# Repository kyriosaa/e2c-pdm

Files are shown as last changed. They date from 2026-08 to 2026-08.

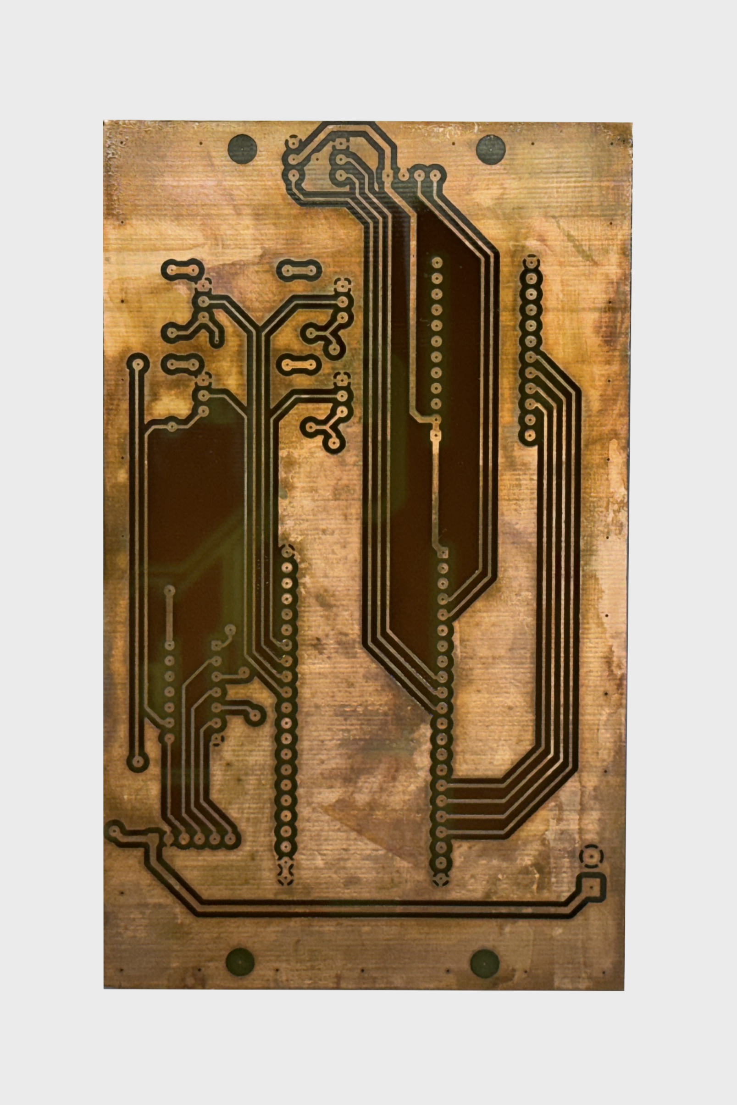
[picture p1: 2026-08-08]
docs/images/rev2.0/mdc_2.1_back.png

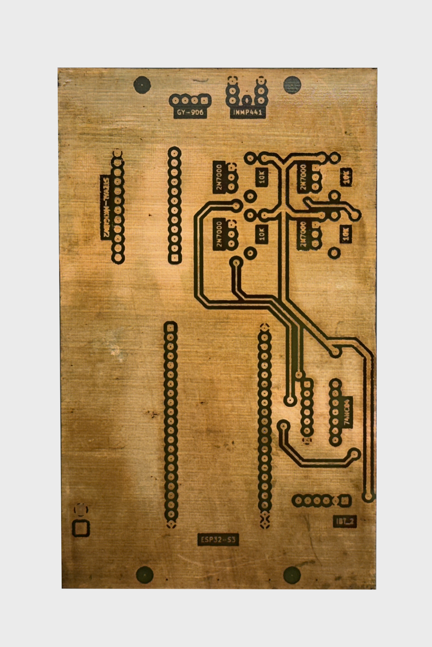
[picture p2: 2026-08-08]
docs/images/rev2.0/mdc_2.1_front.png

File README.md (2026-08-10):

# E2C-PDM — An edge-to-cloud digital twin for predictive maintenance

Thesis project. A three-tier condition-monitoring system built around a
laboratory motor rig: an ESP32-S3 acquisition front-end, a Raspberry Pi
inference tier, and a cloud tier for the digital twin and long-horizon storage.

**Status: data acquisition validated, healthy baseline recorded, no fault data
yet.** The offline feature pipeline runs end to end. Model training is blocked on
seeded-fault data — see
[docs/notes/collection_protocol.md](docs/notes/collection_protocol.md).

---

## Architecture

```
   MOTOR RIG                 EDGE TIER 1            EDGE TIER 2        CLOUD
   ---------                 -----------            -----------        -----
  RS-445PA DC motor
  + BTS7960 driver
        |
  IIS3DWB   26.7 kHz x3 ---+
  INMP441   16 kHz mono ---+--> ESP32-S3 ----USB CDC----> Raspberry Pi ---> InfluxDB
  MLX90614  1 Hz -------- +    (FreeRTOS,   ~200 KB/s    (features,        + digital
                               2 cores,                   inference,         twin
                               raw counts)                cascade gate)
                                    |
                            thermal interlock
                            70 C latched kill
```

Design principle: computation is pushed to the cheapest place. The MCU ships raw
sensor counts and does no unit conversion or feature extraction, which keeps it a
deterministic acquisition front-end and keeps the acquisition path identical
between dataset collection and deployment.

The ESP32→Pi link is infrastructure and is **excluded** from the bandwidth-savings
claim; that claim applies to the Pi→cloud tier only.

## Repository layout

```
edge/
  esp32/firmware/mdc/                  acquisition + safety firmware
  esp32/tools/                         data_catcher.py (host logger), notifier, start_handler
  hardware/edge_asset_monitor_2L/      2-layer PCB, lab-etched (KiCad)
  hardware/edge_asset_monitor_4L/      4-layer PCB + gerbers (KiCad)
  hardware/espressif-kicad-addon/      VENDORED third-party library, see its README
  rpi/                                 Pi-tier scaffolding (early)
cloud/                                 cloud-tier scaffolding (early)
ml/                                    offline pipeline -- see ml/README.md
  studies/                             one-off analyses (audio filtering, integrity)
  notebooks/                           exploratory notebooks
data/                                  UNTRACKED. raw/ interim/ processed/
docs/
  notes/                               decisions + rationale + the quirk
                                       register. READ THIS FIRST.
  figures/                             tracked thesis figures (pipeline/ is generated)
  datasheets/ certifications/          RS-445PA, IIS3DWB, STEVAL-MKI208V1K,
                                       ISO 13732-1, ...
  schematics/ images/                  rev1.0 and rev2.0
references.md                          reference paper bank
```

`data/` is gitignored; sessions are ~4.5 GB each. `docs/notes/` is gitignored
too, so **the design notes linked below are local-only and will not be present
in a clone.** `docs/figures/pipeline/` is gitignored as the pipeline regenerates
it; the rest of `docs/` is tracked.

## Getting oriented

Start with [docs/notes/](docs/notes/):

| Note | What it settles |
|---|---|
| [quirk_register.md](docs/notes/quirk_register.md) | **Read before quoting any number.** The real dataset inventory, known defects, and the measured sensor calibration. |
| [collection_protocol.md](docs/notes/collection_protocol.md) | **How to collect data from here on.** The confound trap, the fault set, the integrity gate. |
| [operating_profile_rationale.md](docs/notes/operating_profile_rationale.md) | Why the rig needs no "real" use case, and what it does need. |
| [motor_signature.md](docs/notes/motor_signature.md) | Measured spectrum, measured sample rates, rig validation against physics. |
| [thermal_channel_confound.md](docs/notes/thermal_channel_confound.md) | Why absolute temperature is unusable and the thermal channel is currently flat. |
| [acoustic_noise_filtering.md](docs/notes/acoustic_noise_filtering.md) | Why spectral subtraction, and why not a notch or high-pass. |
| [overnight_acquisition_rig.md](docs/notes/overnight_acquisition_rig.md) | Acquisition architecture, integrity layers, safety layers, defence Q&A. |
| [thermal_interlock_70c.md](docs/notes/thermal_interlock_70c.md) | Why 70 °C, from ISO 13732-1. |

## Reproducing a recording session

Requires the physical rig. Read
[overnight_acquisition_rig.md](docs/notes/overnight_acquisition_rig.md) §3
before running unattended.

1. Flash `edge/esp32/firmware/mdc/` to the ESP32-S3.
   **Never flash with the 24 V rail energised.** Power sequence: USB first, 24 V
   last; de-energise 24 V first.
2. Set the run parameters and provenance fields at the top of
   `edge/esp32/tools/data_catcher.py` — `SESSION_LABEL`, `RUN_SECONDS`,
   `MOTOR_VOLTAGE_V`, `MECHANICAL_LOAD`, `FAULT_CONDITION`, `ROOM_CONDITION`.
   `ACCEL_FS_G` must match the firmware.
3. `python edge/esp32/tools/data_catcher.py`
   The motor arms after `ARM_DELAY_S` (60 s); that head of the recording is the
   motor-off room-noise reference. No logger means no motor — the firmware
   requires an explicit host arm.
4. Output lands in `data/raw/<label>_<timestamp>/`: `vibration.bin`, `audio.wav`,
   `status.csv`, `packet_index.csv`, `session.json`.
5. Gate the session on integrity before trusting it:
   ```
   python -m ml.sessions <session_name>
   python -m ml.studies.integrity_report
   ```
   Acceptance criteria are in
   [collection_protocol.md](docs/notes/collection_protocol.md).

## Running the offline pipeline

From the repository root. See [ml/README.md](ml/README.md) for detail.

```
pip install -r ml/requirements.txt

python -m ml.sessions                 # gap map + measured sample rates (cached)
python -m ml.data_loader              # per-session sanity check
python -m ml.features                 # gap-aware Welch PSD windows
python -m ml.studies.integrity_report # dataset integrity table

# leave-one-session-out, training pool held to one operating point so the 15 V
# session stays unseen for the novelty check
python -m ml.train_autoencoder --split session \
    --sessions healthy24V_motor_baseline_20260718_001741 \
               healthy24V_motor_baseline_20260719_010905 \
    --holdout  healthy24V_motor_baseline_20260719_010905
python -m ml.evaluate --novelty healthy15V_motor_baseline_20260716_002156
python -m ml.quantize                 # TFLite dynamic + int8
```

Feature extraction needs only numpy + scipy. **Training needs TensorFlow, which
has no Python 3.14 wheels** — use a separate 3.12 environment for the last three
steps; cached features are reusable across both. See ml/README.md.

## Secrets

Copy `.env.example` to `.env` and fill it in. `.env` is gitignored and is the only
place credentials belong.

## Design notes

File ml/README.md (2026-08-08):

# ml/ — offline ML pipeline

Consumes sessions recorded by `edge/esp32/tools/data_catcher.py` from
`data/raw/`, and produces model artifacts for the edge tier.

```
ml/
├── config.py             all knobs; repo-root anchored paths
├── sessions.py           gap map, measured sample rates, status log   <- read this first
├── data_loader.py        memory-mapped session access
├── features.py           gap-aware Welch PSD windows
├── train_autoencoder.py  leave-one-session-out or time split
├── evaluate.py           thresholds, false-positive rate, novelty check
├── quantize.py           TFLite dynamic + int8, accuracy/threshold drop table
├── studies/              one-off analyses (audio filtering, integrity report)
└── notebooks/            exploratory
```

Generated output lives outside the package:

```
data/interim/<session>/index.json      cached gap map + measured rates
data/interim/features/<session>/       cached feature windows
ml/artifacts/                          models, scaler, tflite (gitignored)
docs/figures/pipeline/                      diagnostic plots (gitignored)
docs/figures/<study>/                       tracked thesis figures
```

## Run everything as a module, from the repo root

```
python -m ml.sessions
```

Not `python ml/sessions.py`. The package uses relative imports, and every path in
`config.py` resolves from the repository root rather than the working directory,
so results do not depend on where you happen to be standing.

## Python version — read before installing

**Feature extraction needs only numpy + scipy** and runs on any modern Python,
including 3.14.

**Training, evaluation and quantization need TensorFlow, which does not publish
wheels for Python 3.14.** Those three steps will exit with instructions if TF is
missing. Use a separate 3.12 environment for them:

```
py -3.12 -m venv .venv-train
.venv-train\Scripts\activate
pip install -r ml/requirements.txt
```

Cached features under `data/interim/features/` are plain `.npy` and are shared
between both environments, so there is no need to re-extract.

## Run order

```
pip install -r ml/requirements.txt

# 1. Parse packet_index.csv -> gap map + measured sample rates. Cached; the
#    first run takes ~10 s per session for a 366 MB index.
python -m ml.sessions

# 2. Per-session sanity check: measured ODR, full scale, segment count,
#    motor-off vs running RMS.
python -m ml.data_loader [session]

# 3. Feature windows. ~1.5 min per 6 h session.
python -m ml.features [session ...]

# 4. Train. --split session is leave-one-session-out and is the number to report.
#    Restrict the training pool to ONE operating point so the other stays unseen
#    and can serve as the novelty check. With the three pilot sessions:
python -m ml.train_autoencoder --split session \
    --sessions healthy24V_motor_baseline_20260718_001741 \
               healthy24V_motor_baseline_20260719_010905 \
    --holdout  healthy24V_motor_baseline_20260719_010905

# 5. Thresholds + false-positive rate. --novelty scores the 15 V session, which
#    the model has never seen, as an off-manifold sensitivity check.
python -m ml.evaluate --novelty healthy15V_motor_baseline_20260716_002156

# 6. TFLite export, accuracy drop, and threshold shift under quantization.
python -m ml.quantize

# Anytime: the dataset integrity table.
python -m ml.studies.integrity_report [--markdown]
```

## Three things that are easy to get wrong

**1. `vibration.bin` has no framing and no gap markers.** `data_catcher.py`
validates the header and CRC in memory, then writes *only* the payload. Lost
packets are simply absent, so the file is a splice of discontinuous runs. Cutting
an FFT window across a splice fabricates a broadband transient that looks exactly
like an impulsive mechanical fault. `sessions.contiguous_segments()` is the only
safe source of window offsets.

On-device FIFO overruns are the nastier version of this: samples vanish inside
the sensor while the packet sequence stays perfectly contiguous, so they are
invisible to sequence-gap detection. The segment map breaks on the overrun flag
for exactly this reason.

**2. Never use a nominal sample rate.** The IIS3DWB measures 26 533–26 547 Hz
against a 26 667 Hz datasheet nominal — it runs ~0.45 % slow, consistently. On the
same host clock the audio stream is accurate to a few ppm, which localises the
error to the sensor's oscillator. At nominal the frequency axis is wrong by 2.9 Hz
at the 635 Hz peak. `sessions.measured_odr()` derives the rate from sequence
numbers and host timestamps, which makes it immune to packet loss and to MCU
resets.

**3. Accelerometer full scale is per session.** The pilot sessions were recorded
at ±16 g; everything from 2026-07-30 is ±4 g. `session.json` carries `accel_fs_g`,
and `sessions.accel_fs_g()` falls back by start timestamp for the pilot sessions.
It raises rather than guessing for anything ambiguous. Do not hardcode it.

## Memory

Everything is memory-mapped and converted per window. A 6 h session is 3.2 GB of
int16 vibration; materialising it as float32 `(N, 3)` would need ~7 GB on top of
the raw bytes, so `load_vibration`-style whole-file loading is deliberately absent.
`load_audio()` still reads a whole track (~1.4 GB as float32) because the audio
studies want it; prefer `open_audio()` plus `audio_to_float()` on slices.

## What the current results can and cannot claim

Can: measured rig characterisation, dataset integrity figures, a healthy-data
false-positive operating point, and a sensitivity-to-change demonstration
(train on 24 V, score 15 V).

Cannot: any detection rate, ROC or AUC. There is no fault data. See
[../docs/notes/collection_protocol.md](../docs/notes/collection_protocol.md).

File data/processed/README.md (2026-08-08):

# data/processed/ — analysis-ready derived datasets (untracked)

Reserved for datasets that are downstream of feature extraction and worth
persisting in their own right (e.g. an assembled train/test matrix spanning
several sessions, or denoised audio exports).

Note the distinction from `docs/figures/`: **figures are thesis artifacts and are
tracked**; processed data is an intermediate and is not.

Currently empty.

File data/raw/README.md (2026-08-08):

# data/raw/ — recorded sessions (untracked)

One directory per recording, named `<label>_<YYYYmmdd_HHMMSS>_<Day>`, written by
`edge/esp32/tools/data_catcher.py`. Roughly **4.5 GB per 6-hour session**.

The weekday is a convenience for scanning the directory listing and carries no
meaning downstream. Two constraints it works around: the label stays first
because `ml.train_autoencoder.operating_point()` keys on the first `_`-separated
field, and `session.json`'s `started` stays a bare timestamp because
`ml.sessions.accel_fs_g()` string-compares it against `ACCEL_FS_CHANGED_AFTER`.
The six pilot sessions predate the weekday and keep their original names.

Never renamed after recording: the cached index in `data/interim/<session>/` is
keyed on the directory name.

## Getting sessions onto the analysis machine

Recording happens on a separate machine from analysis, and this directory is
untracked, so sessions travel by removable drive. **Do not drag-and-drop** — use
the export tool, which SHA-256s every file as it writes and leaves the digests
in `export_manifest.json` alongside the data:

```
# recording machine -> drive
python edge/esp32/tools/export_sessions.py E:/pdm_transfer --skip-tests

# analysis machine: copy the drive's contents into data/raw/, including
# export_manifest.json, then verify the copy you will actually use
python edge/esp32/tools/export_sessions.py data/raw --verify
```

Verify `data/raw`, not the drive — verifying the drive only proves the drive is
intact and says nothing about the second copy.

`--verify` exits non-zero on any mismatch, and re-running the export skips files
already present, so an interrupted transfer resumes. Verify before deleting the
source copy: `vibration.bin` is unframed int16 with no checksum of its own, so a
corrupted byte range is indistinguishable from a real impulsive transient once
it reaches the feature extractor.

## Files per session

| File | Contents |
|---|---|
| `vibration.bin` | Bare little-endian int16 x,y,z triplets. **No framing, no gap markers.** Scale with `accel_fs_g` from `session.json`. |
| `audio.wav` | 16 kHz 16-bit mono. First ~60 s is motor-off room reference. |
| `status.csv` | ~0.977 Hz log: obj/amb temperature, motor state, fault code, counters. |
| `packet_index.csv` | Host arrival time, type, seq, n_samples, flags, dropped for **every** packet. This is what makes the gap map possible. ~366 MB. |
| `session.json` | Metadata + integrity summary + acquisition provenance. |

## Read this before analysing anything

`vibration.bin` holds payload bytes only — lost packets are simply absent, so the
file is a splice of discontinuous runs. Windowing across a splice fabricates a
broadband transient that mimics an impulsive fault. Use
`ml.sessions.contiguous_segments()`, never a naive `arange` over the file.

`session.json`'s `vib_capture_ratio` divides by the **nominal** 26 667 Hz ODR and
therefore understates completeness by the sensor's ~0.45 % clock error. For a real
integrity figure use the sequence-derived ratio from `ml.sessions` /
`ml.studies.integrity_report`.

## Current contents

Six 6-hour healthy baselines recorded 2026-07-16 to 07-20 at ±16 g full scale,
plus three short `test_*` rig-shakedown captures from 07-15/16 that are not
analysis data.

| Session | Motor | Capture ratio | CRC errors |
|---|---|---|---|
| `healthy15V_motor_baseline_20260716_002156` | 15 V | 0.9953 | 160 |
| `healthy24V_motor_baseline_20260718_001741` | 24 V | 0.9949 | 83 |
| `day_healthy24V_motor_baseline_20260718_170626` | 24 V, daytime room | 0.9953 | 123 |
| `healthy24V_motor_baseline_20260719_010905` | 24 V | 0.9955 | 115 |
| `healthy24V_motor_baseline_20260720_003416` | 24 V | 0.9946 | **5719** |
| `healthy24V_motor_baseline_20260720_231747` | 24 V | 0.9955 | 375 |

These are **rig validation / pilot data**, not the final healthy baseline: they
predate the ±4 g full-scale change and were recorded with no mechanical load.
See `docs/notes/collection_protocol.md`.

None of them carry the provenance fields (`accel_fs_g`, `motor_voltage_v`,
`mechanical_load`, `fault_condition`, `room_condition`, `notes`) — all six
predate `ACCEL_FS_CHANGED_AFTER`, so `ml.sessions.accel_fs_g()` resolves them to
±16 g by start timestamp. Voltage in the table above comes from the directory
name, which is the only record of it.

### Two things to check before trusting a session

`healthy24V_motor_baseline_20260720_003416` logged **5719 CRC errors**, roughly
50× every other session (5–375). Its capture ratio is normal, so the link was
recovering, but confirm the gap map from `ml.studies.integrity_report` before
using it — link trouble at that rate may have left more or larger splices.

Every `session.json` here also carries a **`measured_odr_hz` field that is not
authoritative**. It was backfilled as `vib_samples / elapsed_s`, which divides
real samples by wall-clock time and so folds packet loss into what looks like a
clock measurement. It happens to land close (26456–26546 Hz) because transport
loss was ~0.001 %, but it is the same conflation `vib_capture_ratio` is warned
about above. Use `ml.sessions.measured_odr()`, which derives the rate from
packet sequence numbers and separates the two.

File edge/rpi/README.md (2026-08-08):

# edge/rpi/ — Raspberry Pi inference tier

**Status: early. One working script, the rest is planned structure.**

The Pi is the inference tier of the cascade. It receives raw sensor counts from
the ESP32 over USB CDC, does unit conversion and feature extraction (deliberately
NOT done on the MCU), runs the local quantized model, and decides per window
whether the local prediction is confident enough or the window should be offloaded
to the cloud tier.

The Pi->cloud link is the one the bandwidth-savings claim applies to. The
ESP32->Pi link is infrastructure and is excluded from that calculation.

## What exists

| Path | Status |
|---|---|
| `pi_edge_twin.py` | **Working.** Subscribes to an MQTT topic, thresholds `rms_vibration`, writes breaches to InfluxDB 3. This is a functional spike of the confidence gate, not the final design. |
| `config/edge_config.py` | Empty stub. |
| `communications/` | Planned: `usb_listener.py`, `cloud_offload.py`. |
| `data_pipeline/` | Planned: `sensor_processor.py`. |
| `inference/` | Planned: `model.py`, `confidence_gate.py`, `alert_handler.py`. |

## Known gaps

- **`pi_edge_twin.py` uses a fixed `VIBRATION_THRESHOLD` on a single scalar RMS.**
  The offline pipeline in `ml/` produces a 1024-bin PSD feature vector and an
  autoencoder reconstruction error. These need to converge — the deployed gate
  should sit on the same feature and the same threshold the thesis derives in
  `ml/evaluate.py`, not on an unrelated hand-set RMS limit.
- **Two secret stores.** `pi_edge_twin.py` imports credentials from the untracked
  `edge/esp32/tools/private.py`; everything newer uses the gitignored `.env` at
  the repo root. Converge on `.env`.
- **Input path is MQTT, not USB.** The current script assumes something else is
  already publishing to MQTT. `communications/usb_listener.py` is the missing
  piece that would make the Pi read the ESP32 directly, matching the architecture
  described in the root README.

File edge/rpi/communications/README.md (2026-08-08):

# Planned

- `usb_listener.py` — read the framed packet stream from the ESP32 over USB CDC.
  The framing is already implemented host-side in
  `edge/esp32/tools/data_catcher.py`; this is that parser minus the file writing.
- `cloud_offload.py` — ship a window to the cloud tier when the local model is
  not confident. This is the link the bandwidth-savings claim measures.

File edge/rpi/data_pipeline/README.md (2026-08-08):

# Planned

- `sensor_processor.py` — raw int16 counts to engineering units, then windowing
  and Welch PSD features.

Must produce **byte-identical features** to `ml/features.py`, or the deployed
model sees a different distribution than it trained on. Import the offline code
rather than reimplementing it; scale using `accel_fs_g` and the measured ODR, not
datasheet nominals (see `ml/README.md`).

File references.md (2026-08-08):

# Bank of reference papers that I've used so far

Calculation of Printed Circuit Board Power Loop Stray Inductance in GaN or High di/dt Applications
https://ieeexplore.ieee.org/document/8337781
> Paper about how the physical geometry and width of the PCB traces directly dictate parasitic stray inductance. Confirms that the only way to prevent overvoltage ringing and electromagnetic interference is by placing ground lines around the PCB and minimizing the magnetic loop area.

Study and Implementation of IIR Notch Filter and Its Applications
https://www.researchgate.net/publication/380544131_Study_and_Implementation_of_IIR_Notch_Filter_and_Its_Applications

High Pass Filter Designation and IT Report
https://www.researchgate.net/publication/236615957_HIGH_PASS_FILTER_DESIGNATION_AND_IT_REPORT

Noise Removal in Speech Processing Using Spectral Subtraction
https://www.researchgate.net/publication/220841101_Noise_Removal_in_Speech_Processing_Using_Spectral_Subtraction

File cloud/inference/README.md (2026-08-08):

# Planned

- `model.py` — the full-precision cloud model.
- `inference_service.py` — API endpoint the Pi offloads to.

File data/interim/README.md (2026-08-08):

# data/interim/ — generated caches (untracked)

Everything here is derived and safe to delete; it will be rebuilt.

```
<session>/index.json    cached gap map, measured sample rates, loss stats
                        (ml.sessions -- rebuild with --rebuild)
features/<session>/     cached feature windows as .npy + meta.json
                        (ml.features)
```

`index.json` is keyed on the session directory name, so renaming a session
orphans its cache. `ml/sessions.py` bumps `CACHE_VERSION` whenever the index
format or segmentation logic changes, which invalidates stale caches
automatically.

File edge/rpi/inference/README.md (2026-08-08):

# Planned

- `model.py` — load and run the int8 TFLite autoencoder from `ml/artifacts/`.
- `confidence_gate.py` — threshold the reconstruction error to decide local vs
  cloud. Use the threshold derived on the **quantized** model
  (`ml/quantize.py` reports both); a float-derived threshold does not keep its
  false-positive rate after quantization.
- `alert_handler.py` — act on confident local detections.

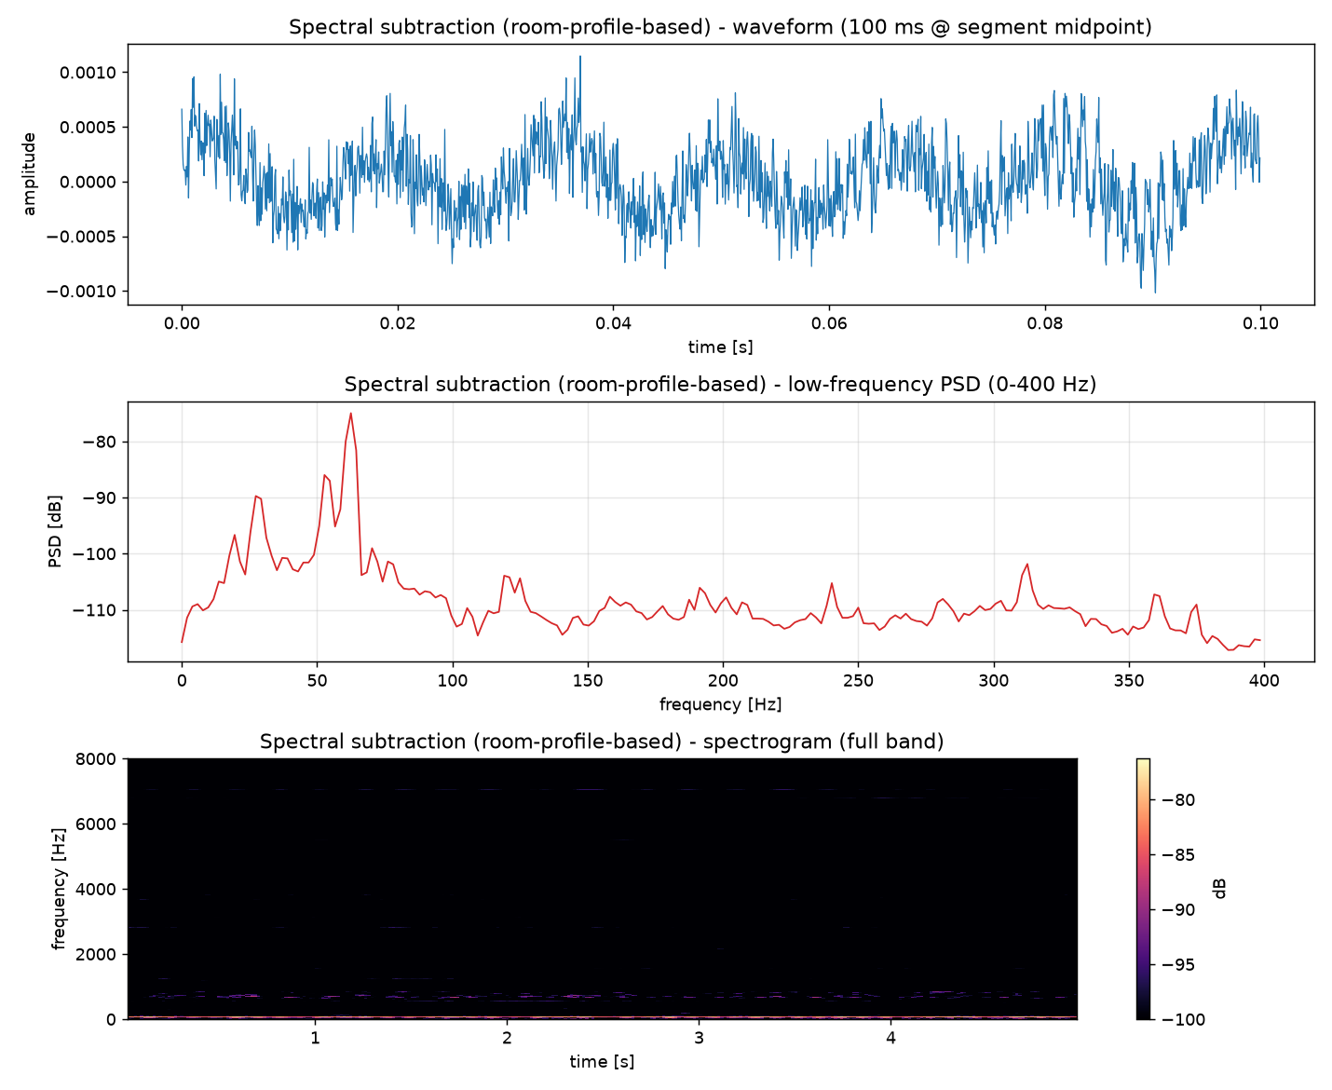
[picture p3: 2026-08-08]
docs/figures/audio_filtering/filter_compare_4way/motor_04_spectral_subtraction.png

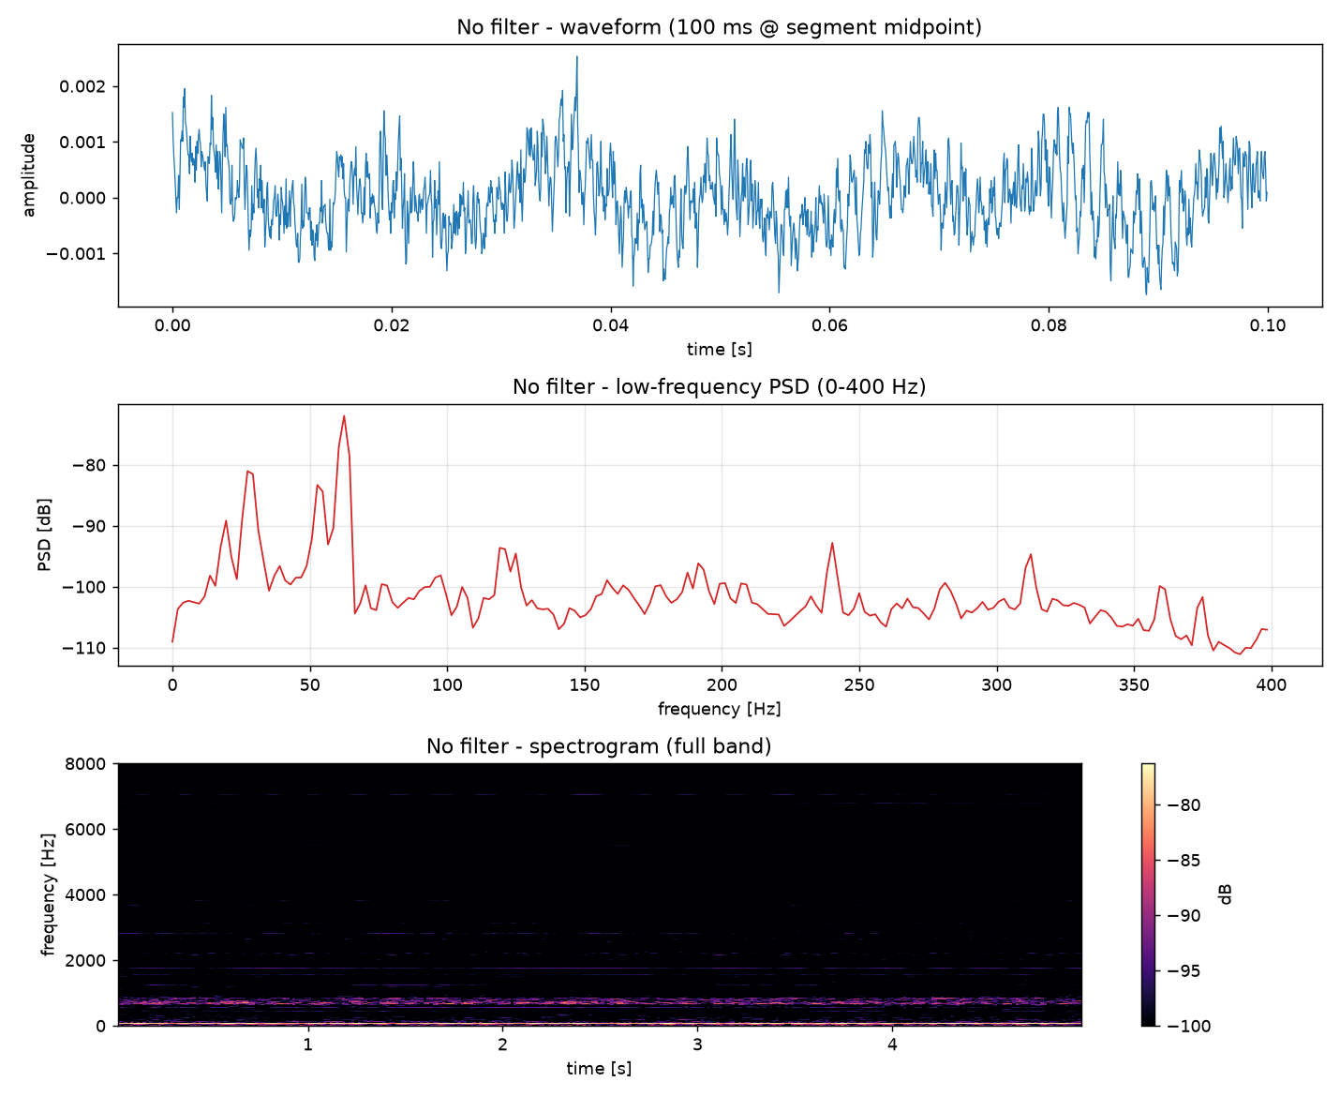
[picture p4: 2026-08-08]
docs/figures/audio_filtering/filter_compare_4way/motor_01_no_filter.png

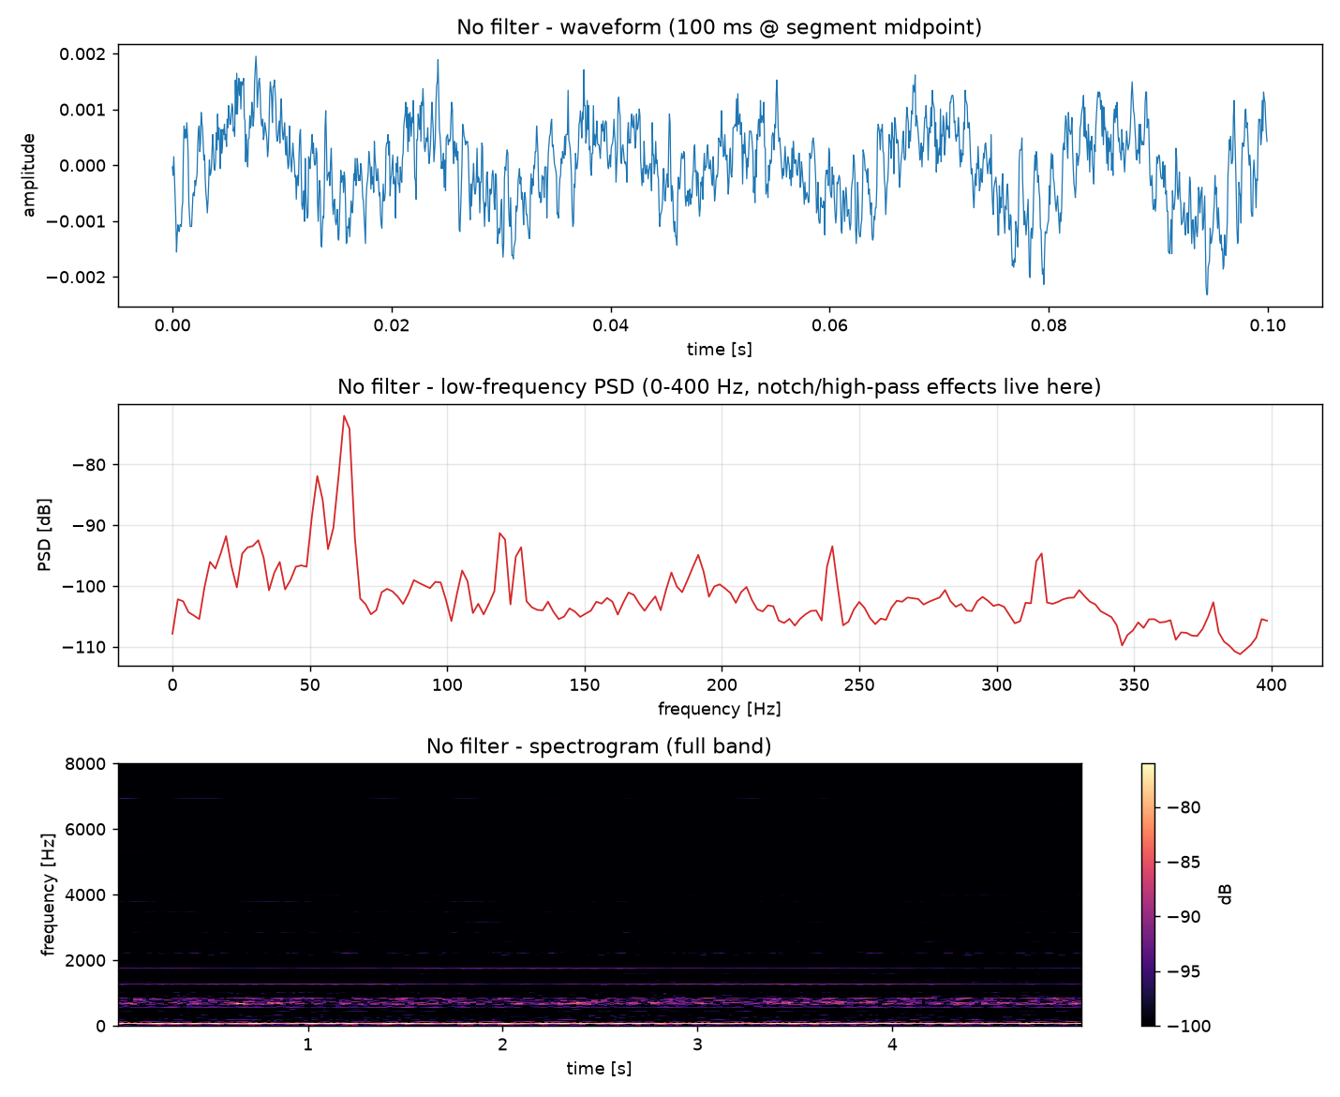
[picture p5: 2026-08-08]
docs/figures/audio_filtering/filter_demo/01_no_filter.png

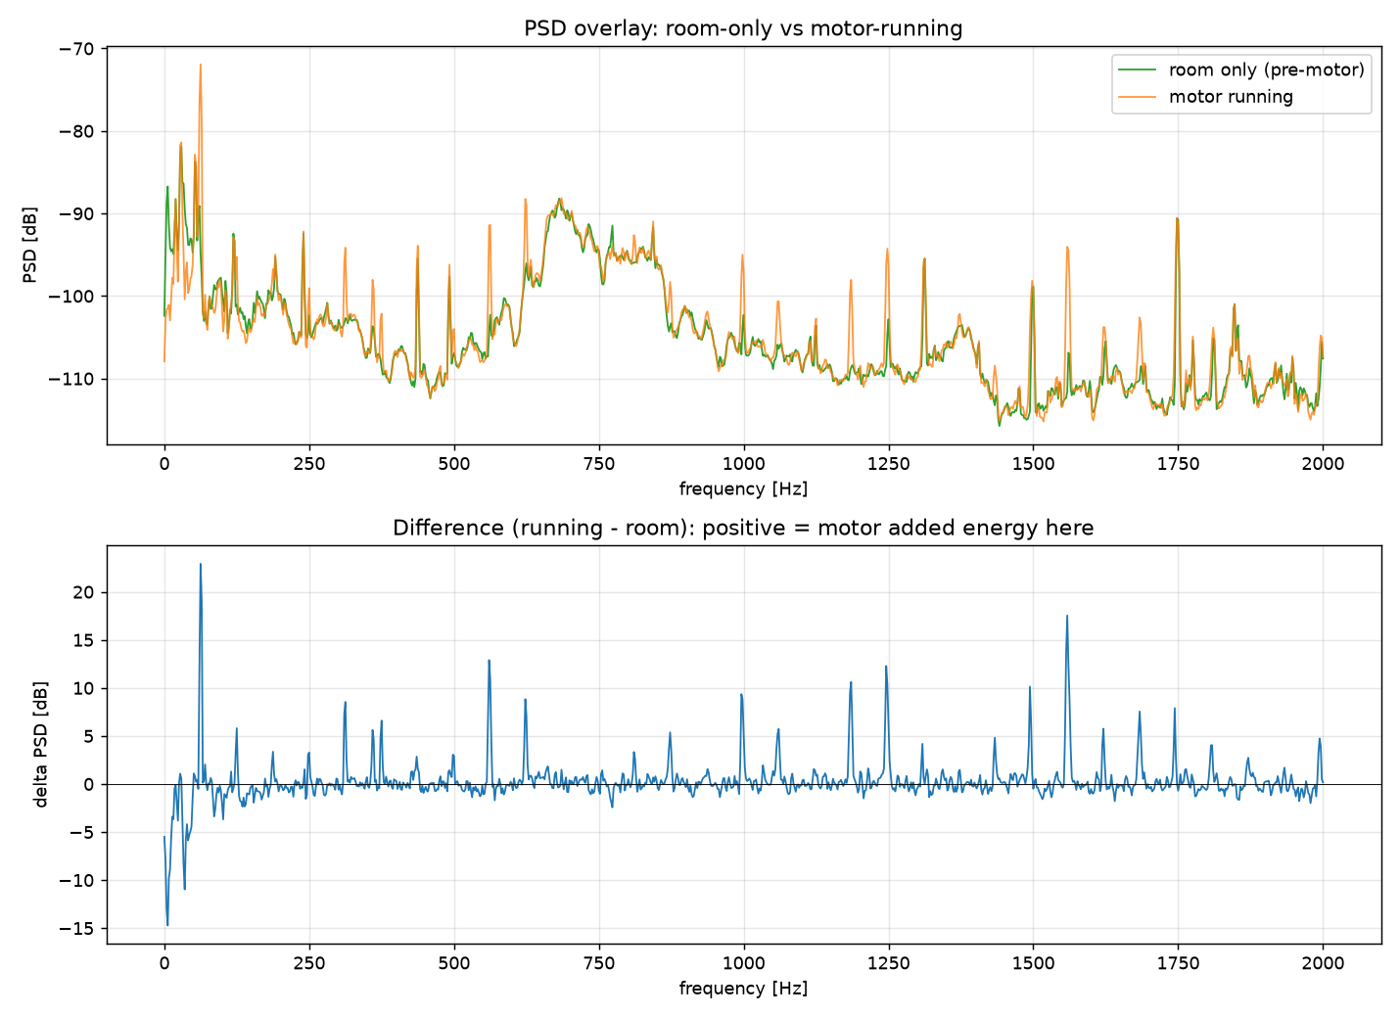
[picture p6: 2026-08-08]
docs/figures/audio_filtering/room_vs_running/05_room_vs_running_psd.png

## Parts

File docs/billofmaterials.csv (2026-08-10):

Id | Designator | Footprint | Quantity | Designation | Supplier and ref
1 | C1, C3, C4, C6, C7, C8, C9 | C_Disc_D5.0mm_W2.5mm_P5.00mm | 7 | 100nF
2 | C2, C5 | CP_Radial_D5.0mm_P2.50mm | 2 | 10uF 16V
3 | C10 | CP_Radial_D5.0mm_P2.50mm | 1 | 470uF 25V
4 | D1 | D_DO-41_SOD81_P7.62mm_Horizontal | 1 | 10V 1W
5 | F1 | Fuseholder_Cylinder-5x20mm_Schurter_0031_8201_Horizontal_Open | 1 | 6A
6 | J1 | JST_XH_B6B-XH-A_1x06_P2.50mm_Vertical | 1 | Conn_01x06
7 | J2, J3, J4 | Altech_AK100_1x02_P5.00mm | 3 | Screw_Terminal_01x02
8 | Q1, Q2, Q3, Q4 | TO-92_Inline_Wide | 4 | 2N7000
9 | Q5 | TO-220-3_Vertical | 1 | IRF4905
10 | Q6 | TO-220-3_Vertical | 1 | NDP6020P
11 | R1, R2, R3, R4 | R_Axial_DIN0207_L6.3mm_D2.5mm_P7.62mm_Horizontal | 4 | 2.2k
12 | R8, R9, R10, R11, R14, R15 | R_Axial_DIN0207_L6.3mm_D2.5mm_P7.62mm_Horizontal | 6 | 100k
13 | R12 | R_Axial_DIN0207_L6.3mm_D2.5mm_P7.62mm_Horizontal | 1 | 10k
14 | R13 | R_Axial_DIN0207_L6.3mm_D2.5mm_P7.62mm_Horizontal | 1 | 15k
15 | U1 | XCVR_ESP32-S3-DEVKITC-1-N16R8V | 1 | ESP32-S3-DEVKITC-1-N16R8V
16 | U2 | DIP-6_W7.62mm | 1 | INMP441
17 | U3 | PinSocket_1x04_P2.54mm_Vertical | 1 | GY-906
18 | U4 | DIP-24_W15.24mm | 1 | STEVAL-MKIGIBV2
19 | U5 | DIP-14_W7.62mm | 1 | 74HC04
20 | U6 | PinSocket_1x03_P2.54mm_Vertical | 1 | ACS712-30A

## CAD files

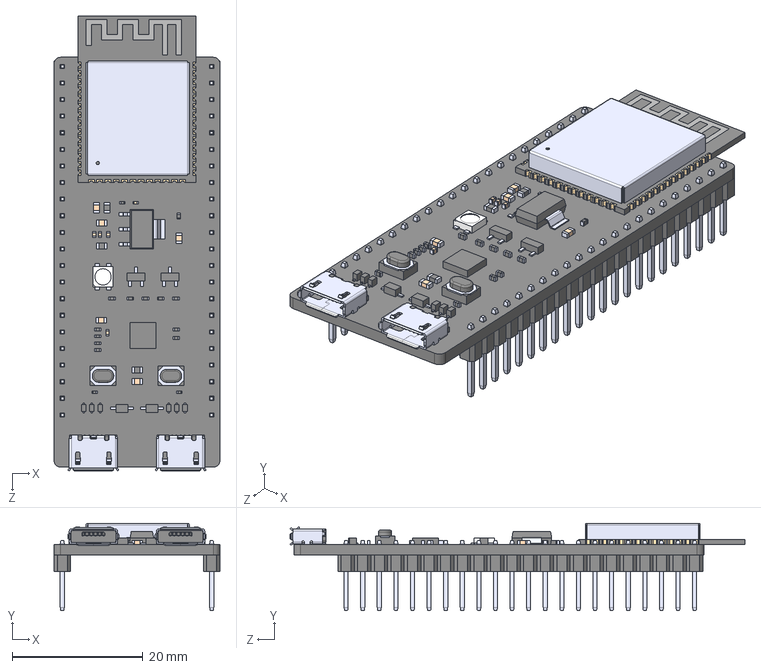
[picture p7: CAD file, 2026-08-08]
edge/hardware/edge_asset_monitor_4L/ESP32-S3-DEVKITC-1-N16R8V.step
25.4 x 13.4 x 69.6 mm

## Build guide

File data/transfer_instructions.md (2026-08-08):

On this machine, run:

python edge/esp32/tools/export_sessions.py E:/pdm_transfer --skip-tests

once done, move USB to other machine and copy everything off the USB into that machine's data/raw/ folder

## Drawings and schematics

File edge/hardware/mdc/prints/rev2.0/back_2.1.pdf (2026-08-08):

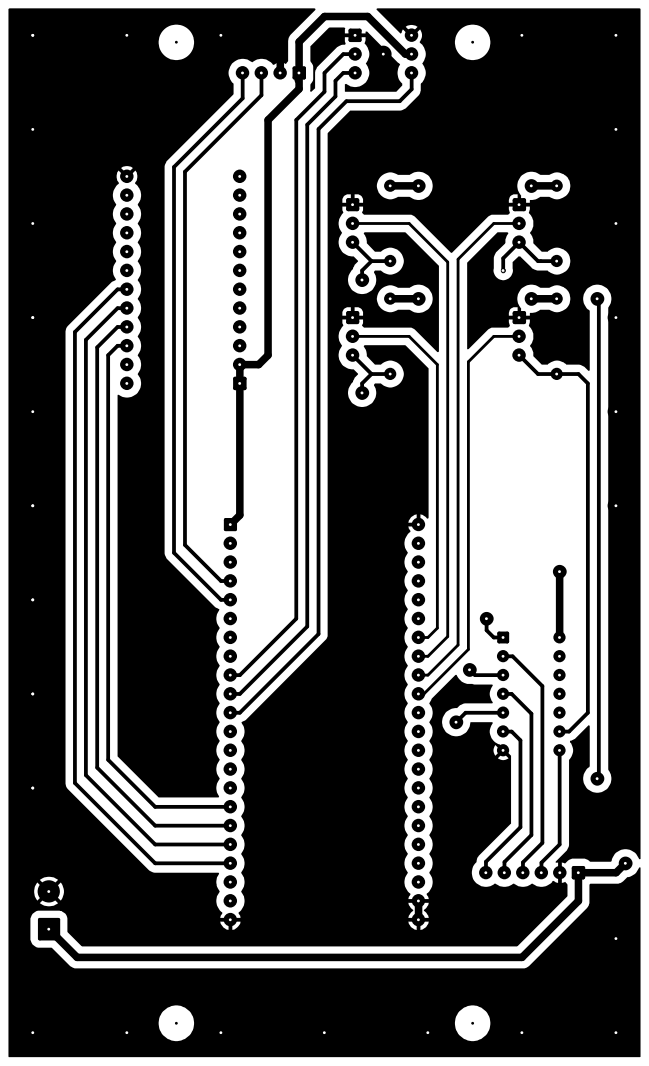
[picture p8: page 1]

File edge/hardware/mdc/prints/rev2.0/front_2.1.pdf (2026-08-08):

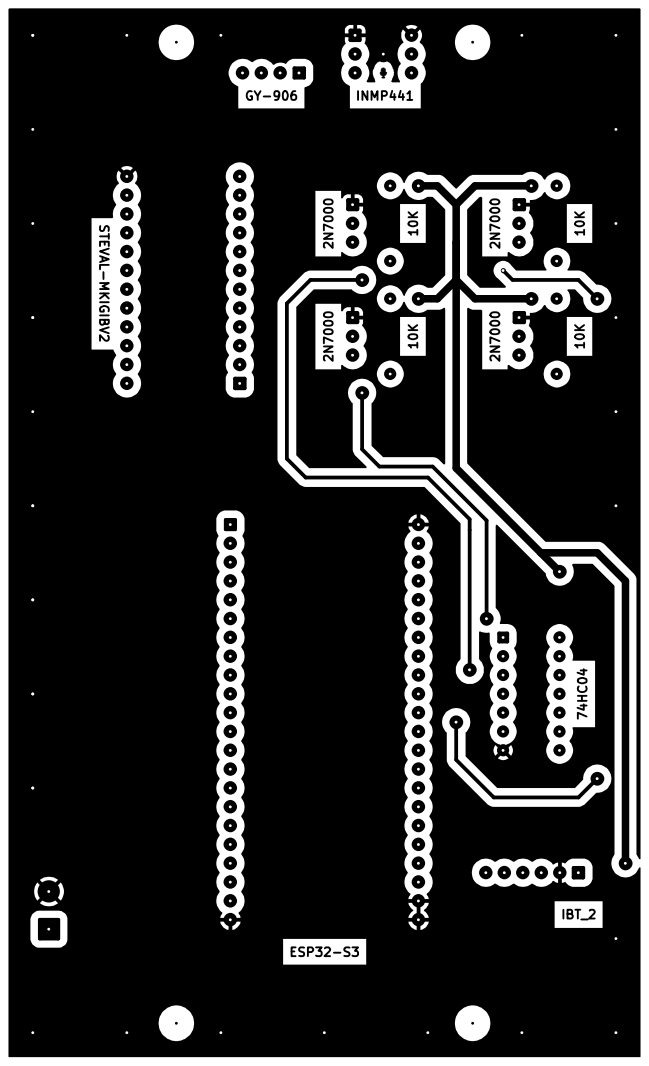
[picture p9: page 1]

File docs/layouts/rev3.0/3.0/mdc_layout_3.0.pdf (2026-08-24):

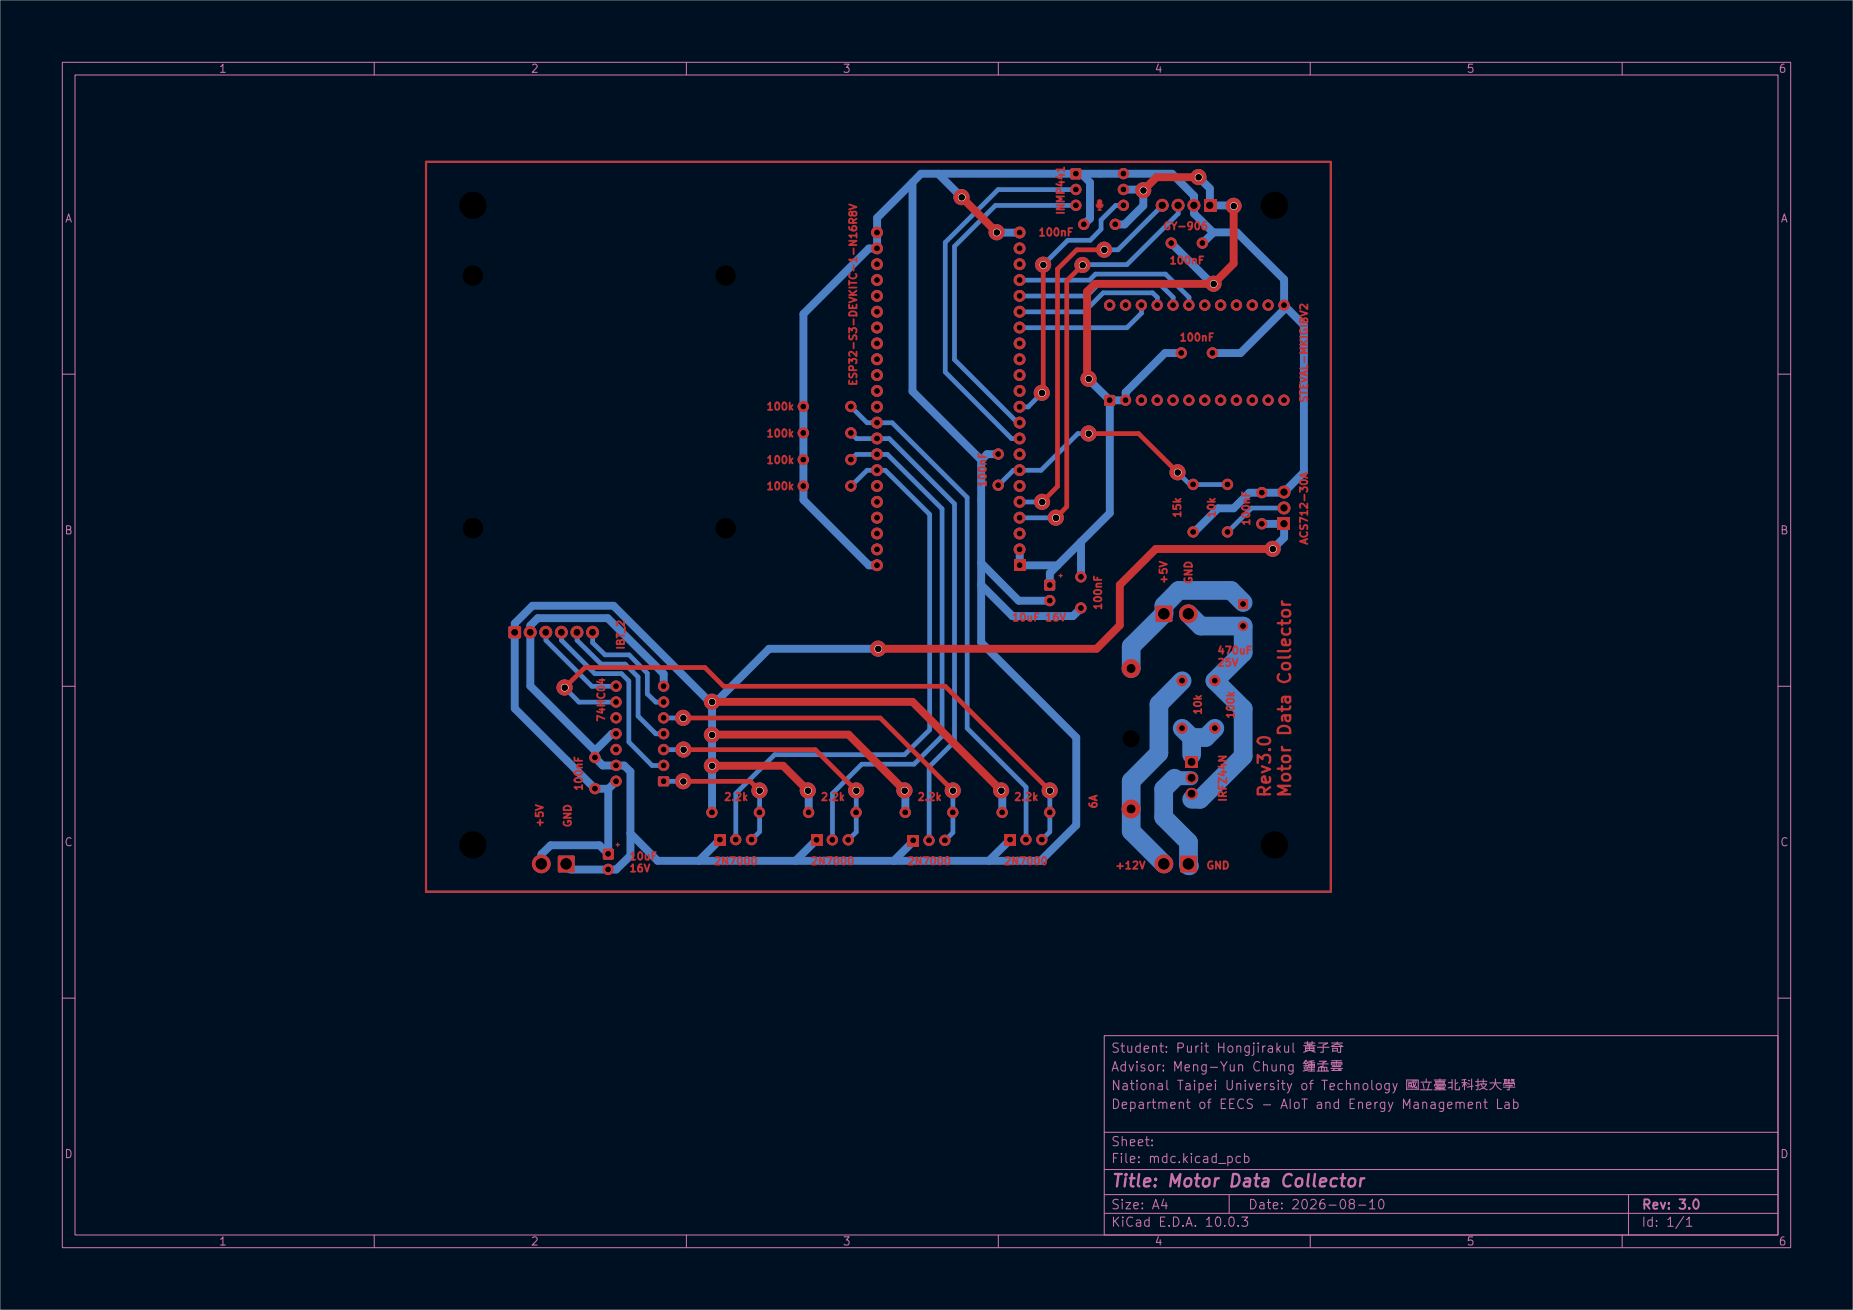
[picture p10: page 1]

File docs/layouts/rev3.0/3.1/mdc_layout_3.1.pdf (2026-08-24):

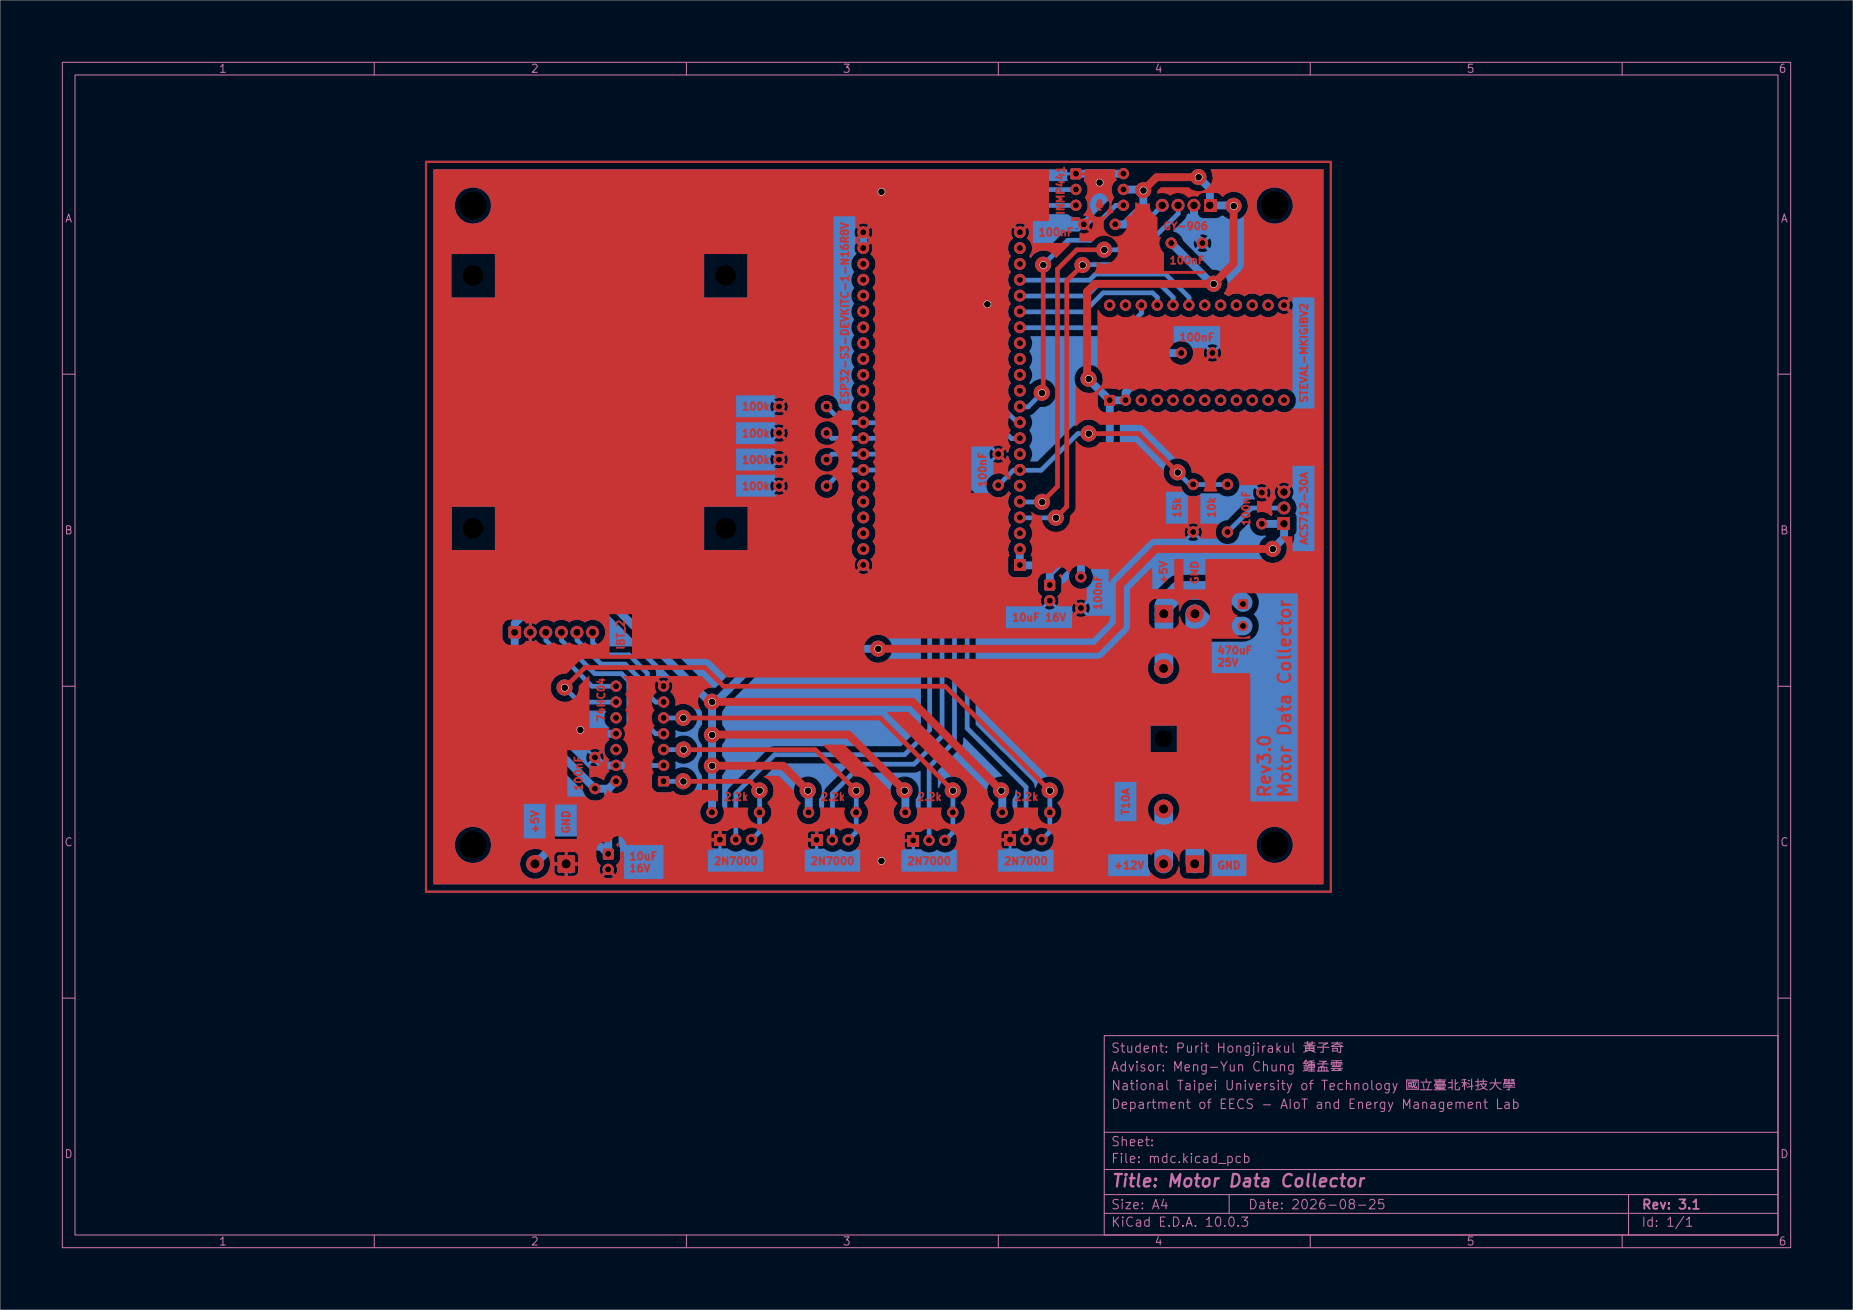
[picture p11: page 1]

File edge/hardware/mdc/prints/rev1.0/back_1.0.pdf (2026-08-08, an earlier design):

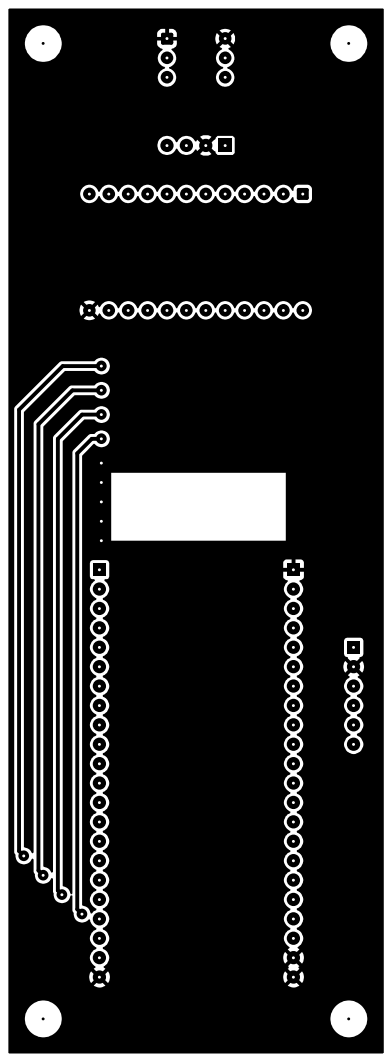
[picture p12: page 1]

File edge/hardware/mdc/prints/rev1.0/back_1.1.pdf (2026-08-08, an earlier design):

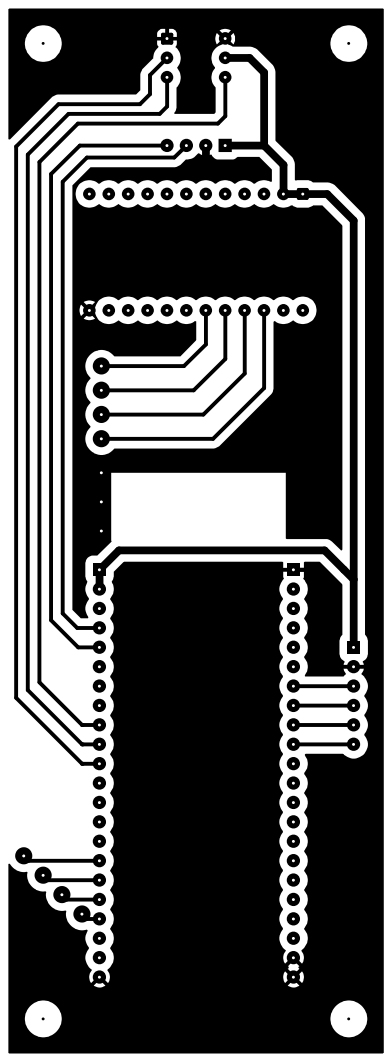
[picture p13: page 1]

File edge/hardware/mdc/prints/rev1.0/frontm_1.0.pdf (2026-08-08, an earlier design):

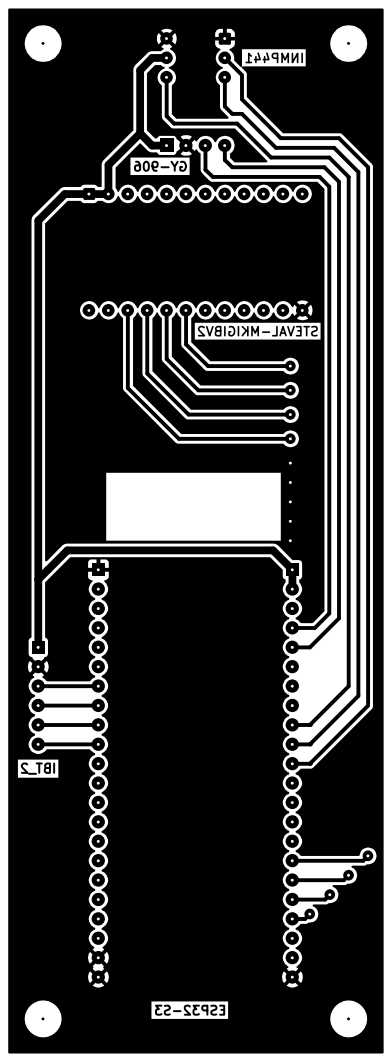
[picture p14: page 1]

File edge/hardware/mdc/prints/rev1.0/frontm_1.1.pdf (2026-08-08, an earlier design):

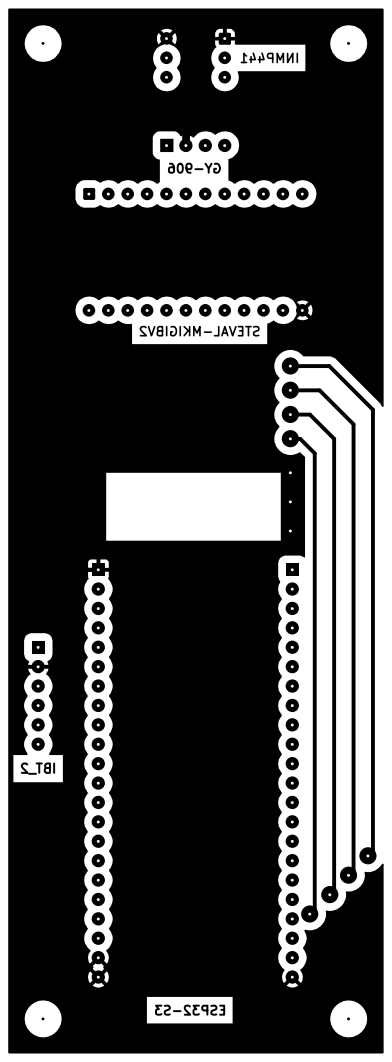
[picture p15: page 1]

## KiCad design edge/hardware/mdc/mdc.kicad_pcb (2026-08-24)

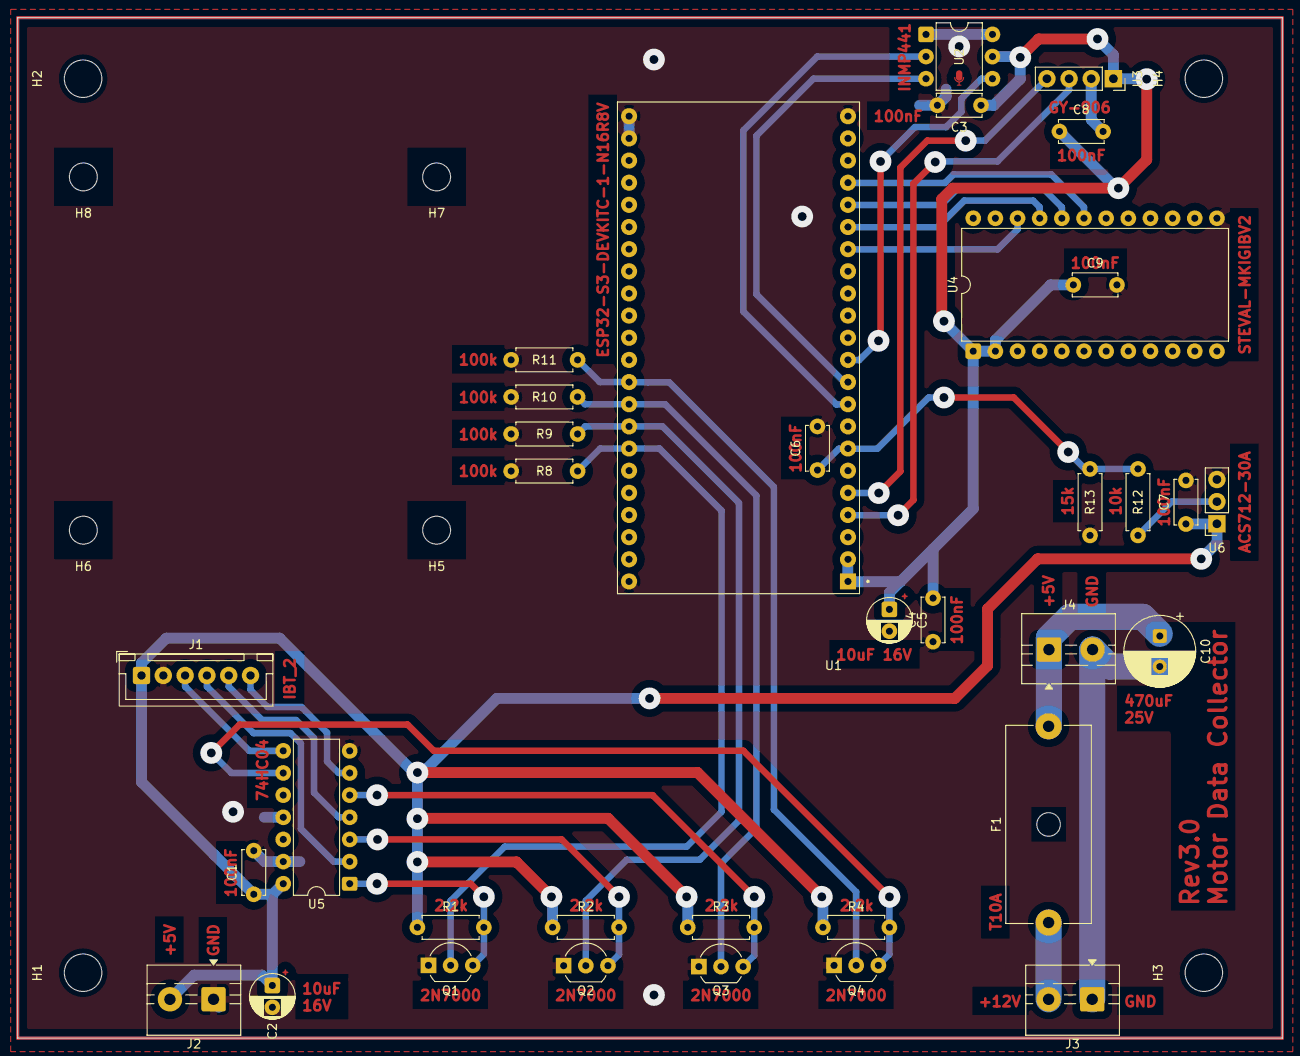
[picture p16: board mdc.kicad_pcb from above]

Board: 2 copper layers, 145.0 x 117.0 mm, 43 parts (0 on the bottom side), 29 nets.

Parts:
C1, C3, C4, C6, C7, C8, C9: 100nF; C_Disc_D5.0mm_W2.5mm_P5.00mm
C2, C5: 10uF 16V; CP_Radial_D5.0mm_P2.50mm
C10: 470uF 25V; CP_Radial_D8.0mm_P3.50mm
F1: T10A; Fuseholder_Cylinder-5x20mm_Schurter_0031_8201_Horizontal_Op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
H1, H2, H3, H4: MountingHole; MountingHole_4.3mm_M4
H5, H6, H7, H8: MountingHole; MountingHole_3.2mm_M3
J1: Conn_01x06; JST_XH_B6B-XH-A_1x06_P2.50mm_Vertical
J2, J3, J4: Conn_01x02; TerminalBlock_MaiXu_MX126-5.0-02P_1x02_P5.00mm
Q1, Q2, Q3, Q4: 2N7000; TO-92_Inline_Wide
R1, R2, R3, R4: 2.2k; R_Axial_DIN0207_L6.3mm_D2.5mm_P7.62mm_Horizontal
R8, R9, R10, R11: 100k; R_Axial_DIN0207_L6.3mm_D2.5mm_P7.62mm_Horizontal
R12: 10k; R_Axial_DIN0207_L6.3mm_D2.5mm_P7.62mm_Horizontal
R13: 15k; R_Axial_DIN0207_L6.3mm_D2.5mm_P7.62mm_Horizontal
U1: ESP32-S3-DEVKITC-1-N16R8V; XCVR_ESP32-S3-DEVKITC-1-N16R8V
U2: INMP441; DIP-6_W7.62mm
U3: GY-906; PinSocket_1x04_P2.54mm_Vertical
U4: STEVAL-MKIGIBV2; DIP-24_W15.24mm
U5: 74HC04; DIP-14_W7.62mm
U6: ACS712-30A; PinSocket_1x03_P2.54mm_Vertical

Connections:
+3V3: C3.1, C4.2, C5.1, C8.1, C9.1, U1.J1_1 (3V3), U1.J1_2 (3V3), U2.5 (VDD), U3.1 (VIN), U4.1 (VDD), U4.2 (VDDIO)
+5V: C1.1, C2.1, C7.1, J1.1, J2.2, R1.1, R2.1, R3.1, R4.1, U5.14 (VCC), U6.1 (VCC)
+12V: F1.1, J3.2
+12V_FUSED: C10.1, F1.2, J4.1
GND: C1.2, C2.2, C3.2, C4.1, C5.2, C6.2, C7.2, C8.2, C9.2, J1.2, J2.1, Q1.1 (S), Q2.1 (S), Q3.1 (S), Q4.1 (S), R8.2, R9.2, R10.2, R11.2, R13.2, U1.J1_22 (GND), U1.J3_1 (GND), U1.J3_21 (GND), U1.J3_22 (GND), U2.1 (L/R), U2.6 (GND), U3.2 (GND), U4.13 (GND), U5.7 (GND), U5.11, U5.13, U6.3 (GND)
GPIO38: Q4.2 (G), R11.1, U1.J3_10 (GPIO38)
GPIO39: Q3.2 (G), R10.1, U1.J3_9 (MTCK/GPIO39)
GPIO40: Q2.2 (G), R9.1, U1.J3_8 (MTDO/GPIO40)
GPIO41: Q1.2 (G), R8.1, U1.J3_7 (MTDI/GPIO41)
I2C_SCL: U1.J1_4 (GPIO4), U3.3 (SCL)
I2C_SDA: U1.J1_5 (GPIO5), U3.4 (SDA)
I2S_SCK: U1.J1_10 (GPIO17), U2.3 (SCK)
I2S_SD: U1.J1_11 (GPIO18), U2.4 (SD)
I2S_WS: U1.J1_9 (GPIO16), U2.2 (WS)
ISENSE: C6.1, R12.2, R13.1, U1.J1_7 (GPIO7)
LPWM: J1.5, U5.4
LPWM_IN: Q2.3 (D), R2.2, U5.3
L_EN: J1.3, U5.8
L_EN_IN: Q4.3 (D), R4.2, U5.9
MOTOR_GND: C10.2, J3.1, J4.2
unnamed: R12.1, U6.2 (OUT)
RPWM: J1.4, U5.2
RPWM_IN: Q1.3 (D), R1.2, U5.1
R_EN: J1.6, U5.6
R_EN_IN: Q3.3 (D), R3.2, U5.5
SPI_CS: U1.J1_19 (GPIO13), U4.19 (CS)
SPI_SCL: U1.J1_18 (GPIO12), U4.20 (SCL)
SPI_SDA: U1.J1_17 (GPIO11), U4.21 (SDA)
SPI_SDO: U1.J1_16 (GPIO10), U4.22 (SDO-SAO)

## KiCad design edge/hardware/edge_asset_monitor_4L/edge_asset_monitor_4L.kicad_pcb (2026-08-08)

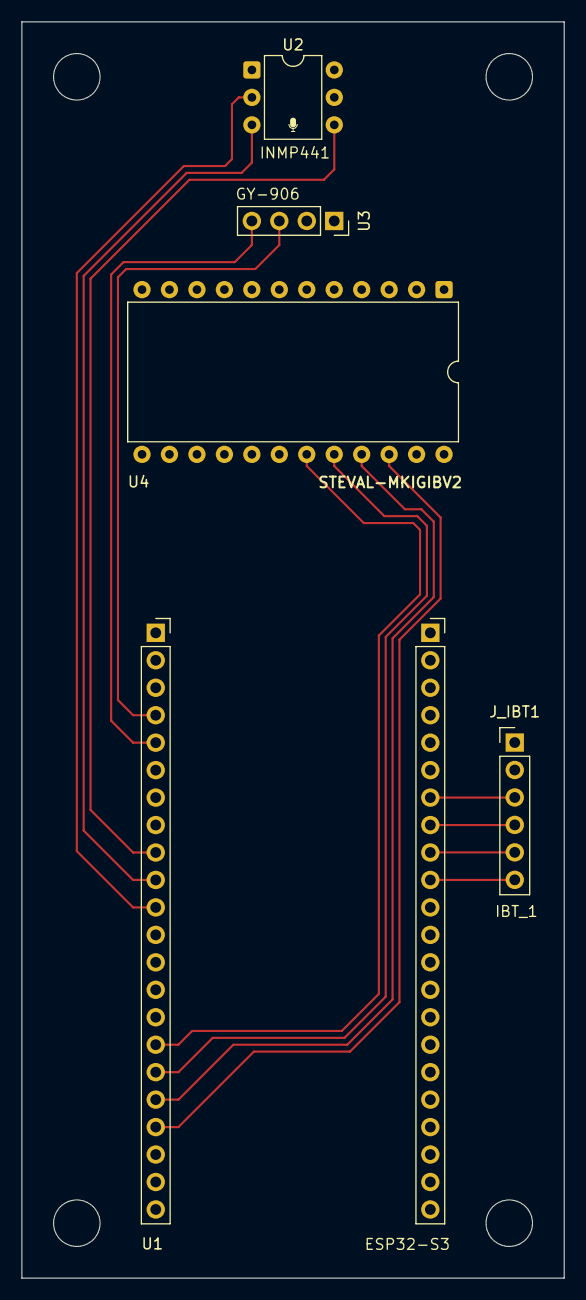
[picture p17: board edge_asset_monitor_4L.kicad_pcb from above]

Board: 4 copper layers, 50.2 x 116.2 mm, 9 parts (0 on the bottom side), 15 nets.

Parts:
H1, H2, H3, H4: MountingHole; MountingHole_4.3mm_M4
J_IBT1: Conn_01x06_Pin; PinHeader_1x06_P2.54mm_Vertical
U1: ESP32-S3-DEVKITC-1-N16R8V; PinSocket_1x22_P2.54mm_Vertical
U2: DIP-6_W7.62mm
U3: PinSocket_1x04_P2.54mm_Vertical
U4: DIP-24_W15.24mm

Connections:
+3V3: J_IBT1.1, U1.J1_1 (3V3), U1.J1_2 (3V3), U2.5 (VDD), U3.1 (VIN), U4.1 (VDD), U4.2 (VDDIO)
GND: J_IBT1.2, U1.J1_22 (GND), U1.J3_1 (GND), U1.J3_21 (GND), U1.J3_22 (GND), U2.1 (L/R), U2.6 (GND), U3.2 (GND), U4.13 (GND)
unnamed: J_IBT1.3, U1.J3_7 (MTDI/GPIO41)
unnamed: J_IBT1.4, U1.J3_8 (MTDO/GPIO40)
unnamed: J_IBT1.5, U1.J3_9 (MTCK/GPIO39)
unnamed: J_IBT1.6, U1.J3_10 (GPIO38)
unnamed: U1.J1_4 (GPIO4), U3.3 (SCL)
unnamed: U1.J1_5 (GPIO5), U3.4 (SDA)
unnamed: U1.J1_16 (GPIO10), U4.19 (CS)
unnamed: U1.J1_17 (GPIO11), U4.20 (SCL)
unnamed: U1.J1_18 (GPIO12), U4.21 (SDA)
unnamed: U1.J1_19 (GPIO13), U4.22 (SDO-SAO)
unnamed: U1.J1_9 (GPIO16), U2.4 (SD)
unnamed: U1.J1_10 (GPIO17), U2.3 (SCK)
unnamed: U1.J1_11 (GPIO18), U2.2 (WS)

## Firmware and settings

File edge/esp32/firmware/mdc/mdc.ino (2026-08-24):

// ESP32-S3
// motor dataset collection rig
//
// IDE settings:
//   Tools -> "USB CDC On Boot: DISABLED"  (Serial = UART0 -> CH343 bridge)
//
// note!!
// the BTS7960s on the IBT-2 have internal pull-downs on IN and INH, 
// so ESP32 pins floating during boot or flashing read LOW at the driver and the bridge stays disabled
//
//   POWER SEQUENCING RULE: plug in the USB first, then turn on the power supply. never flash with 24V present

#include <SPI.h>
#include <Wire.h>
#include <Adafruit_MLX90614.h>
#include <driver/i2s.h>
#include <esp_task_wdt.h>
#include <esp_system.h>
#include <driver/gpio.h>

// GY-906 (MLX90614) - temperature (I2C)
#define MLX90614_SCL 4
#define MLX90614_SDA 5

// vibration (SPI). Two ST boards, both in the path:
//   STEVAL-MKI208V1K  carries the IIS3DWB itself, sensor soldered centre-board,
//                     adhesive-mounted on the motor frame. This is the part the
//                     datasheet numbers refer to.
//   STEVAL-MKIGIBV2   DIL24 adapter it cables into; what the PCB actually
//                     footprints (see edge/hardware/*/sensors.kicad_sch).
#define IIS3DWB_CS  13
#define IIS3DWB_SCL 12  // SCK
#define IIS3DWB_SDA 11  // MOSI
#define IIS3DWB_SDO 10  // MISO

// INMP441 - acoustic (I2S)
#define I2S_SD      18
#define I2S_SCK     17
#define I2S_WS      16
#define I2S_PORT    I2S_NUM_0

// IBT_2 - motor driver
#define MOTOR_RPWM 41
#define MOTOR_LPWM 40
#define MOTOR_R_EN 38
#define MOTOR_L_EN 39

// ACS712-30A on the motor's +12 V lead, read through the 10k/15k divider on the
// sensors sheet (net ISENSE). The sensor swings 0-5 V and this ADC reads to
// ~3.1 V, so the divider is not optional -- without it the pin is over-driven.
#define CURRENT_SENSE_PIN 7                                  // ADC1_CH6

// run config
static const float    TRIP_TEMP_C     = 70.0f;                      // kills system at 70 deg (based on the ISO-13732-1 burn threshold)
static const uint32_t TEMP_STALE_MS   = 5000;                       // sensor-lost timeout
static const uint32_t MAX_RUN_MS      = 6UL * 60UL * 60UL * 1000UL; // 6 h cap
// Running duty, -255..255. This is the THROTTLE. Lower it to run slower --
// do not use the PSU current limit for that. A current-limited motor changes
// speed on its own as friction and temperature drift, so the operating point
// would not be stable within a session, let alone between them.
// Effective motor voltage is roughly supply x MOTOR_SPEED/255.
static const int      MOTOR_SPEED     = 150;

// Kick-start. Breaking away needs more torque than keeping turning, so a low
// MOTOR_SPEED may not start the motor at all -- it sits and squeals instead.
// Start at KICK_SPEED for KICK_MS, then ease down to MOTOR_SPEED. If
// MOTOR_SPEED >= KICK_SPEED there is nothing to kick and this does nothing.
// Non-blocking: the loop keeps running, so 'X' still stops the motor mid-kick.
// Kept only as high as it needs to be -- a harder kick than necessary just
// slams the coupling and shakes the frame on every start.
// 2026-08-24: 160 (~7.5 V effective) would not break away, but the motor ran
// fine wired straight to the 12 V PSU. Raised to 255 -- and the motor STILL
// did not break away, with pwm_duty telemetry confirming 255 was applied. So
// the shortfall is in the drive electronics, not the commanded duty; 255 is
// kept as the correct kick regardless. See quirk register 2.14.
static const int      KICK_SPEED      = 255;
static const uint32_t KICK_MS         = 1500;   // full duty, to break away
static const uint32_t RAMP_MS         = 2000;   // then ease down to MOTOR_SPEED

// Why ease down rather than step down: breaking away from rest needs far more
// torque than staying turning, so the motor can be spinning happily at full
// duty and still stall if the duty is yanked straight back to MOTOR_SPEED
// before it has picked up speed. The ramp lets it settle instead.

static const uint32_t WDT_TIMEOUT_MS  = 5000;                       // watchdog timeout

// Current sensing. The 30 A part gives 66 mV/A, which the divider scales to
// ~39.6 mV/A at the pin -- coarse for a motor drawing 1-6 A, so the reading is
// averaged over CURRENT_SAMPLES rather than taken as a single sample. The burst
// also spans several PWM periods, which matters: the drive is chopped, so one
// instantaneous sample says nothing useful about the mean current.
static const float    CURRENT_DIVIDER  = 15.0f / (10.0f + 15.0f);   // 0.6
static const float    ACS712_MV_PER_A  = 66.0f;                     // 30 A variant
static const int      CURRENT_SAMPLES  = 64;

// Zero-current output, measured at boot while the motor is definitely off.
// Nominally VCC/2 x divider = 1500 mV, but the real figure depends on the 5 V
// rail and the part's own offset, so it is measured rather than assumed. A
// reading far from ~1500 mV means the sensor or the divider is not connected.
static uint32_t       currentZeroMv    = 0;

// Accelerometer full scale. CHANGED 2026-07-30 from +/-16 g to +/-4 g.
//
// Measured on the three 6 h pilot sessions recorded at +/-16 g: running RMS is
// 0.043 g (15 V) to 0.056 g (24 V) with a worst-case peak of 1.16 g. At
// +/-16 g (0.488 mg/LSB) an RMS of 0.056 g is only ~115 LSB, i.e. about 7 of
// the 16 available bits were carrying signal.
//
// +/-4 g gives 0.122 mg/LSB -- 4x finer resolution, ~9 bits at the same RMS --
// while still leaving 3.4x headroom over the observed 1.16 g peak. +/-2 g was
// rejected as too tight for the impulsive transients that seeded faults are
// expected to produce.
//
// IF THIS IS CHANGED AGAIN: data recorded either side of the change is not
// resolution-comparable. data_catcher.py writes ACCEL_FS_G into every
// session.json so analysis code scales each session correctly; the two values
// must be kept in step (ml/config.py documents both).
//
// IIS3DWB CTRL1_XL (10h). Verified against DS12569 Rev 8, Table 28 (register
// layout) and Table 30 (full-scale selection), p.32:
//   bit 7..5  XL_EN[2:0]   101 = accelerometer enabled, 000 = power-down
//   bit 4     must be 0
//   bit 3..2  FS[1:0]_XL   00 = +/-2 g (default), 01 = +/-16 g,
//                          10 = +/-4 g,           11 = +/-8 g
//   bit 1     LPF2_XL_EN   0 = first filtering stage output
//   bit 0     must be 0
//   0xA4 = 1010_0100 -> FS_XL=01 -> +/-16 g   (pilot sessions 2026-07-16..20)
//   0xA8 = 1010_1000 -> FS_XL=10 -> +/-4 g    (current)
static const uint8_t  IIS3DWB_CTRL1_XL_VAL = 0xA8;                  // XL on @ 26.7 kHz, FS +/-4 g
static const float    ACCEL_FS_G           = 4.0f;                  // must match the register above

// CTRL1_XL as read back from the device after configuration; 0xFF until
// setupIIS3DWB() has run. Shipped in every status packet so the host records
// the full scale the hardware reports rather than the one it was told to
// expect. Four sessions were recorded at +/-16 g while every session.json
// claimed +/-4 g, because the constants above were edited but the build was
// never flashed and nothing compared intent against hardware.
static volatile uint8_t iisCtrl1XL = 0xFF;
#define REQUIRE_HOST_ARM 1       

// fault handler
enum FaultCode : uint8_t {
  FAULT_NONE          = 0,
  FAULT_OVERTEMP      = 1,
  FAULT_TEMP_SENSOR   = 2,   // GY-906 stopped answering
  FAULT_RUNTIME_DONE  = 3,   // planned end of run
  FAULT_BAD_RESET     = 4,   // rebooted via WDT/panic/brownout (stay off)
  FAULT_VIB_INIT      = 5,   // IIS3DWB WHO_AM_I or CTRL1_XL readback failed
  FAULT_HOST_STOP     = 6,   // logger sent 'X' or disconnected intentionally
};

static volatile uint8_t faultCode = FAULT_NONE;

// binary packet protocol
enum PacketType : uint8_t { PKT_VIB = 0, PKT_AUDIO = 1, PKT_STATUS = 2 };

// flags bits
#define FLAG_FIFO_OVERRUN 0x01
#define FLAG_FAULTED      0x02

struct __attribute__((packed)) PacketHeader {
  uint16_t magic;        // 0xA55A
  uint8_t  type;         // PacketType
  uint8_t  flags;
  uint32_t seq;          // per-stream sequence number
  uint16_t payloadLen;   // bytes
  uint16_t dropped;      // samples lost since previous packet (0xFFFF = unknown)
};

struct __attribute__((packed)) StatusPayload {
  float    objTempC;
  float    ambTempC;
  uint8_t  motorRunning;
  uint8_t  faultCode;
  uint32_t uptimeS;
  uint32_t vibPackets;
  uint32_t audioPackets;
  uint16_t fifoOverruns;
  uint32_t txDropped;    // whole packets skipped bcs USB TX buffer was full
  uint8_t  ctrl1XL;      // CTRL1_XL read back from the sensor; host derives FS
  int16_t  pwmDuty;      // duty actually applied right now, -255..255. The host
                         // records this instead of trusting MOTOR_SPEED, and it
                         // shows the kick and ramp as they happen.
  int16_t  currentMa;    // motor current, milliamps, signed (direction matters)
};

static SemaphoreHandle_t serialMutex;
static uint32_t seqVib = 0, seqAudio = 0, seqStatus = 0;
static volatile uint16_t fifoOverrunCount = 0;
static volatile uint32_t txDroppedPackets = 0;   // whole packets skipped bcs USB full

static uint16_t crc16ccitt(const uint8_t *d, size_t n, uint16_t crc = 0xFFFF) {
  for (size_t i = 0; i < n; i++) {
    crc ^= (uint16_t)d[i] << 8;
    for (int b = 0; b < 8; b++)
      crc = (crc & 0x8000) ? (crc << 1) ^ 0x1021 : (crc << 1);
  }
  return crc;
}

static void sendPacket(uint8_t type, uint8_t flags, uint32_t seq,
                       const uint8_t *payload, uint16_t len, uint16_t dropped) {
  PacketHeader h;
  h.magic = 0xA55A;
  h.type = type;
  h.flags = flags | (faultCode != FAULT_NONE ? FLAG_FAULTED : 0);
  h.seq = seq;
  h.payloadLen = len;
  h.dropped = dropped;

  uint16_t crc = crc16ccitt((const uint8_t *)&h, sizeof(h));
  crc = crc16ccitt(payload, len, crc);

  const size_t total = sizeof(h) + len + 2;
  xSemaphoreTake(serialMutex, portMAX_DELAY);
  size_t w = Serial.write((const uint8_t *)&h, sizeof(h));
  if (w == sizeof(h)) {
    w += Serial.write(payload, len);
    w += Serial.write((const uint8_t *)&crc, 2);
  }
  if (w != total) txDroppedPackets++;
  xSemaphoreGive(serialMutex);
}

// motor control
// pins are forced safe before anything else happens in setup()
static volatile bool motorRunning = false;

static const gpio_num_t MOTOR_PINS[4] = {
  (gpio_num_t)MOTOR_R_EN, (gpio_num_t)MOTOR_L_EN,
  (gpio_num_t)MOTOR_RPWM, (gpio_num_t)MOTOR_LPWM
};

static void motorPinsSafe() {
  // release a pad hold from a previous fault bcs it survives soft resets
  // otherwise the pinMode/digitalWrite functions silently do nothing
  for (auto p : MOTOR_PINS) gpio_hold_dis(p);
  pinMode(MOTOR_R_EN, OUTPUT); digitalWrite(MOTOR_R_EN, LOW);
  pinMode(MOTOR_L_EN, OUTPUT); digitalWrite(MOTOR_L_EN, LOW);
  pinMode(MOTOR_RPWM, OUTPUT); digitalWrite(MOTOR_RPWM, LOW);
  pinMode(MOTOR_LPWM, OUTPUT); digitalWrite(MOTOR_LPWM, LOW);
}

// Start-up shaping. rampEndsMs == 0 means "not starting up, hold runSpeed".
static uint32_t kickEndsMs = 0;      // end of the full-duty kick
static uint32_t rampEndsMs = 0;      // end of the ease-down
static uint32_t lastRampMs = 0;      // throttles how often the duty is rewritten
static int      runSpeed   = 0;      // duty to settle at

// The duty actually being applied right now, shipped in every status packet so
// the host records what the board is really doing rather than what the firmware
// constant claims. Same reasoning as the CTRL1_XL readback above: a declared
// constant is not evidence. Signed, -255..255.
static volatile int16_t appliedDuty = 0;

// Averaged ADC read in millivolts. analogReadMilliVolts applies the chip's
// factory ADC calibration, so this is real millivolts rather than raw counts
// that would need a per-board scale factor.
static uint32_t readSenseMv() {
  uint32_t acc = 0;
  for (int i = 0; i < CURRENT_SAMPLES; i++) acc += analogReadMilliVolts(CURRENT_SENSE_PIN);
  return acc / CURRENT_SAMPLES;
}

static int16_t readCurrentMa() {
  const float mvPerA = ACS712_MV_PER_A * CURRENT_DIVIDER;    // ~39.6 mV/A at the pin
  float ma = ((float)readSenseMv() - (float)currentZeroMv) / mvPerA * 1000.0f;
  if (ma >  32000.0f) ma =  32000.0f;                        // keep it in int16
  if (ma < -32000.0f) ma = -32000.0f;
  return (int16_t)ma;
}

static void motorApply(int speed) {
  if (speed >= 0) { analogWrite(MOTOR_LPWM, 0);     analogWrite(MOTOR_RPWM, speed);  }
  else            { analogWrite(MOTOR_RPWM, 0);     analogWrite(MOTOR_LPWM, -speed); }
  appliedDuty = (int16_t)speed;
}

static void motorKill(uint8_t code) {
  kickEndsMs = rampEndsMs = 0;    // a kill mid-start-up must not be undone
  digitalWrite(MOTOR_R_EN, LOW);
  digitalWrite(MOTOR_L_EN, LOW);
  analogWrite(MOTOR_RPWM, 0);
  analogWrite(MOTOR_LPWM, 0);
  appliedDuty = 0;
  // clamp the pads LOW in hardware so nothing short of a power cycle can re-enable the driver after a fault
  for (auto p : MOTOR_PINS) gpio_hold_en(p);
  motorRunning = false;
  if (faultCode == FAULT_NONE) faultCode = code;  // first fault wins, latched
}

static void motorStart(int speed) {          // -255 to 255
  if (faultCode != FAULT_NONE) return;       // latched, no restart until reset
  digitalWrite(MOTOR_R_EN, HIGH);
  digitalWrite(MOTOR_L_EN, HIGH);
  runSpeed = speed;
  if (abs(speed) < KICK_SPEED && (KICK_MS || RAMP_MS)) {
    motorApply(speed >= 0 ? KICK_SPEED : -KICK_SPEED);
    kickEndsMs = millis() + KICK_MS;
    rampEndsMs = kickEndsMs + RAMP_MS;
    lastRampMs = 0;
    if (rampEndsMs == 0) rampEndsMs = 1;     // 0 is the "settled" sentinel
  } else {
    motorApply(speed);                       // already full duty, nothing to do
    kickEndsMs = rampEndsMs = 0;
  }
  motorRunning = true;
}

// IIS3DWB
// hardware FIFO, continuous mode, drained in bursts
#define IIS3DWB_WHO_AM_I    0x0F  // must read 0x7B
#define IIS3DWB_FIFO_CTRL3  0x09
#define IIS3DWB_FIFO_CTRL4  0x0A
#define IIS3DWB_CTRL1_XL    0x10
#define IIS3DWB_CTRL3_C     0x12
#define IIS3DWB_FIFO_STAT1  0x3A
#define IIS3DWB_FIFO_STAT2  0x3B
#define IIS3DWB_FIFO_TAG    0x78  // tag + 6 data bytes follow (auto-increment)

static const SPISettings iisSPI(8000000, MSBFIRST, SPI_MODE0);

static void iisWrite(uint8_t reg, uint8_t val) {
  SPI.beginTransaction(iisSPI);
  digitalWrite(IIS3DWB_CS, LOW);
  SPI.transfer(reg & 0x7F);
  SPI.transfer(val);
  digitalWrite(IIS3DWB_CS, HIGH);
  SPI.endTransaction();
}

static uint8_t iisRead(uint8_t reg) {
  SPI.beginTransaction(iisSPI);
  digitalWrite(IIS3DWB_CS, LOW);
  SPI.transfer(reg | 0x80);
  uint8_t v = SPI.transfer(0x00);
  digitalWrite(IIS3DWB_CS, HIGH);
  SPI.endTransaction();
  return v;
}

static bool setupIIS3DWB() {
  pinMode(IIS3DWB_CS, OUTPUT);
  digitalWrite(IIS3DWB_CS, HIGH);
  SPI.begin(IIS3DWB_SCL, IIS3DWB_SDO, IIS3DWB_SDA, IIS3DWB_CS);
  delay(20);

  iisWrite(IIS3DWB_CTRL3_C, 0x01);            // SW_RESET
  delay(20);
  if (iisRead(IIS3DWB_WHO_AM_I) != 0x7B) return false;

  iisWrite(IIS3DWB_CTRL3_C,   0x44);          // BDU + IF_INC
  iisWrite(IIS3DWB_FIFO_CTRL3, 0x0A);         // batch XL at 26.7 kHz
  iisWrite(IIS3DWB_FIFO_CTRL4, 0x06);         // FIFO continuous mode
  iisWrite(IIS3DWB_CTRL1_XL,  IIS3DWB_CTRL1_XL_VAL);   // XL on @ 26.7 kHz, FS per ACCEL_FS_G

  // Verify the full scale actually took. A blind write here is invisible until
  // someone measures 1 g and finds it in the wrong place, by which point the
  // sessions are already recorded. Failing init latches FAULT_VIB_INIT, which
  // holds the motor off, so a mis-scaled run stops before it starts.
  delay(5);
  iisCtrl1XL = iisRead(IIS3DWB_CTRL1_XL);
  if (iisCtrl1XL != IIS3DWB_CTRL1_XL_VAL) return false;

  return true;
}

// returns unread FIFO words
// sets *overrun if the FIFO wrapped (data lost)
static uint16_t fifoStatus(bool *overrun) {
  SPI.beginTransaction(iisSPI);
  digitalWrite(IIS3DWB_CS, LOW);
  SPI.transfer(IIS3DWB_FIFO_STAT1 | 0x80);
  uint8_t s1 = SPI.transfer(0x00);
  uint8_t s2 = SPI.transfer(0x00);
  digitalWrite(IIS3DWB_CS, HIGH);
  SPI.endTransaction();
  *overrun = (s2 & 0x40) != 0;                // FIFO_OVR_IA
  return ((uint16_t)(s2 & 0x03) << 8) | s1;   // DIFF_FIFO[9:0]
}

// CORE 1 vibration task
// drains the FIFO in chunk-word bursts and ships each burst as one packet
// sample loss will show up as the overrun flag + dropped counter instead of just silently vanishing
static void vibTask(void *) {
  esp_task_wdt_add(NULL);
  const int CHUNK = 64;                        // 64 samples = 2.4 ms of data
  static int16_t buf[CHUNK * 3];

  for (;;) {
    esp_task_wdt_reset();
    bool ovr = false;
    uint16_t avail = fifoStatus(&ovr);
    if (ovr) fifoOverrunCount++;

    while (avail >= CHUNK) {
      int n = 0;
      SPI.beginTransaction(iisSPI);
      for (int i = 0; i < CHUNK; i++) {
        digitalWrite(IIS3DWB_CS, LOW);
        SPI.transfer(IIS3DWB_FIFO_TAG | 0x80);
        uint8_t tag = SPI.transfer(0x00);
        uint8_t d[6];
        for (int j = 0; j < 6; j++) d[j] = SPI.transfer(0x00);
        digitalWrite(IIS3DWB_CS, HIGH);
        if (((tag >> 3) & 0x1F) == 0x02) {     // accelerometer data word
          buf[n * 3 + 0] = (int16_t)((d[1] << 8) | d[0]);
          buf[n * 3 + 1] = (int16_t)((d[3] << 8) | d[2]);
          buf[n * 3 + 2] = (int16_t)((d[5] << 8) | d[4]);
          n++;
        }
      }
      SPI.endTransaction();

      sendPacket(PKT_VIB,
                 ovr ? FLAG_FIFO_OVERRUN : 0,
                 seqVib++,
                 (const uint8_t *)buf, n * 6,
                 ovr ? 0xFFFF : 0);            // exact loss unknown on overrun
      ovr = false;
      esp_task_wdt_reset();
      avail = fifoStatus(&ovr);
      if (ovr) fifoOverrunCount++;
    }
    vTaskDelay(1);                           
  }
}
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
void loop() {
  static uint32_t lastStatusMs = 0;
  static bool armRequested = (REQUIRE_HOST_ARM == 0);
  static bool tempProven = false;
  static bool motorWasStarted = false;
  esp_task_wdt_reset();

  // host commands
  while (Serial.available()) {
    int c = Serial.read();
    if (c == 'G' || c == 'g') armRequested = true;
    if (c == 'X' || c == 'x') motorKill(FAULT_HOST_STOP);
    if (c == 'R' || c == 'r') {
      // pads stay held LOW through the restart and ESP_RST_SW counts as a clean boot, 
      // so the fault latch is released without touching the physical RESET button
      motorKill(FAULT_HOST_STOP);
      delay(50);
      esp_restart();
    }
  }

  // gated start (armed + interlock proven alive + no fault, once only)
  if (!motorWasStarted && armRequested && tempProven && faultCode == FAULT_NONE) {
    motorStart(MOTOR_SPEED);
    motorWasStarted = true;
  }

  // Start-up shaping: full duty, then ease down to runSpeed. Driven from the
  // loop rather than with delay() inside motorStart so the loop stays live --
  // 'X' still stops the motor part-way through, and status packets keep going.
  if (rampEndsMs && motorRunning) {
    uint32_t now = millis();
    if ((int32_t)(now - rampEndsMs) >= 0) {
      motorApply(runSpeed);                        // settled
      kickEndsMs = rampEndsMs = 0;
    } else if ((int32_t)(now - kickEndsMs) >= 0 &&
               (now - lastRampMs) >= 50) {         // 50 ms steps, not every pass
      lastRampMs = now;
      const int hi = (runSpeed >= 0) ? KICK_SPEED : -KICK_SPEED;
      const uint32_t into = now - kickEndsMs;
      motorApply(hi + (int)((int32_t)(runSpeed - hi) * (int32_t)into / (int32_t)RAMP_MS));
    }
  }

  // 1 Hz (temperature + interlocks)
  if (millis() - lastStatusMs >= 1000) {
    lastStatusMs = millis();

    float t = mlx.readObjectTempC();
    float a = mlx.readAmbientTempC();
    if (!isnan(t)) {
      objTempC = t;
      ambTempC = isnan(a) ? ambTempC : a;
      lastTempOkMs = millis();
      tempProven = true;

      // NOTE: this trips on a SINGLE over-threshold reading, with no debounce.
      // That is fail-safe in the correct direction (a spurious low reading
      // cannot suppress a trip -- the next 1 Hz sample would still catch it).
      //
      // But the pilot sessions show the MLX90614 producing roughly 2 spurious
      // single-sample excursions per 6 h run, in which obj and amb move
      // together by 1.5-2.6 C for exactly one sample and then return. At the
      // present ~25 C operating point a 2.6 C excursion is nowhere near the
      // 70 C threshold, so no spurious trip is possible today. Once a
      // mechanical load raises the steady-state case temperature, consider
      // requiring 2 consecutive over-threshold readings before latching --
      // one extra second above the threshold is thermally negligible, and it
      // stops a single glitch from ending an overnight run.
      // Not implemented yet: it is a change to safety-critical behaviour and
      // should be a deliberate decision, not a side effect.
      if (motorRunning && objTempC >= TRIP_TEMP_C)
        motorKill(FAULT_OVERTEMP);
    }

    // stop the motor if the interlock sensor goes silent
    if (motorRunning && millis() - lastTempOkMs > TEMP_STALE_MS)
      motorKill(FAULT_TEMP_SENSOR);

    if (motorRunning && millis() > MAX_RUN_MS)
      motorKill(FAULT_RUNTIME_DONE);

    // status packet
    StatusPayload s;
    s.objTempC      = objTempC;
    s.ambTempC      = ambTempC;
    s.motorRunning  = motorRunning ? 1 : 0;
    s.faultCode     = faultCode;
    s.uptimeS       = millis() / 1000;
    s.vibPackets    = seqVib;
    s.audioPackets  = seqAudio;
    s.fifoOverruns  = fifoOverrunCount;
    s.txDropped     = txDroppedPackets;
    s.ctrl1XL       = iisCtrl1XL;
    s.pwmDuty       = appliedDuty;
    s.currentMa     = readCurrentMa();
    sendPacket(PKT_STATUS, 0, seqStatus++, (const uint8_t *)&s, sizeof(s), 0);
  }

  vTaskDelay(pdMS_TO_TICKS(100));
}

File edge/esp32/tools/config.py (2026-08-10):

# Every setting for this rig that changes between runs, in one place.
#
# Edit this file, not the scripts. data_catcher.py, start_handler.py and
# export_sessions.py all read from here, so they can no longer disagree with
# each other -- which they did: start_handler.py sat on COM3 while
# data_catcher.py had been moved to COM6, and COM3 opens perfectly well on this
# machine (it is Intel AMT serial-over-LAN), so 'start' reported that it had
# rebooted the board while writing 'R' into nothing.
#
# What is deliberately NOT here: the wire protocol (packet header layout, status
# struct, fault codes, CTRL1_XL bit decoding) and the export manifest format.
# Those are contracts with the firmware and with files already on disk. They
# change when the firmware or the format changes, not when you set up a run, and
# they belong beside the code that parses them.
#
# SMTP credentials stay in private.py, which is gitignored. This file is
# tracked, so nothing secret goes in it.

import os

# ---------------------------------------------------------------------------
# Serial link                            data_catcher.py + start_handler.py
# ---------------------------------------------------------------------------
# List the ports with:  python -m serial.tools.list_ports -v
# The board is the CH343 USB bridge. Do not guess from the number -- COM1 and
# COM3 on this machine are a motherboard port and Intel AMT SOL, and both open
# without error while being attached to nothing.
SERIAL_PORT = 'COM6'
BAUD_RATE   = 3000000

# ---------------------------------------------------------------------------
# Where recordings land                  data_catcher.py + export_sessions.py
# ---------------------------------------------------------------------------
# Anchored to this file so it resolves the same regardless of cwd. The catcher
# writes here; export_sessions.py reads from here.
RAW_ROOT = os.path.normpath(os.path.join(
    os.path.dirname(os.path.abspath(__file__)), '..', '..', '..', 'data', 'raw'))

# ---------------------------------------------------------------------------
# One session                                             data_catcher.py
# ---------------------------------------------------------------------------
# Motor replaced 2026-08-09. The new part is rated 12 V / 20 000 rpm nominal,
# 1.4 A no-load, 5.5 A starting. Everything recorded before that date is a
# DIFFERENT MOTOR and is not a baseline for anything recorded after it.
SESSION_LABEL = 'healthy12V'
# SESSION_LABEL = 'test'
RUN_SECONDS   = int(2 * 3600)       # 2hr run -- short enough that a cell sits
                                    # inside one ambient condition. A 6 h run
                                    # started in the evening ends in the small
                                    # hours and spans both.
ARM_DELAY_S   = 60                  # 60s wait time before motor starts running

# ---------------------------------------------------------------------------
# Unattended back-to-back sessions                       start_handler.py
# ---------------------------------------------------------------------------
REBOOT_WAIT_S = 4                   # settle time after 'R' before launching

# Gap between the end of one auto session and the start of the next. Lets the
# motor and the driver cool back to ambient so every session starts from the
# same thermal state instead of inheriting the previous run's heat.
AUTO_GAP_S = int(1 * 3600)

# A session that ends this fast did not run -- data_catcher aborted (bad port,
# full-scale mismatch, latched fault). Without this, auto mode would happily
# restart a broken run every hour all night and produce nothing.
AUTO_MIN_SESSION_S = 300

# How often the auto thread checks whether the session has ended. Keep it well
# below AUTO_MIN_SESSION_S or a short failed run gets rounded up past the guard.
AUTO_POLL_S = 2
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

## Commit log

2026-08-08 rev3.0 schematics
    [generator_load.kicad_sch, mdc.kicad_sch, microcontroller.kicad_sch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]
2026-08-09 finish rev3.0 PCB layout + data collector script changes + firmware changes
    [generator_load.kicad_sch, mdc.kicad_pcb, microcontroller.kicad_sch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]
2026-08-10 added rev3.0 schematics
2026-08-10 added rev3.0 PCB layout + moved PCB layouts to layouts folder
2026-08-10 added datasheets + bill of materials
    [billofmaterials.csv]
2026-08-10 update rev3.0 schematic and layout
    [generator_load.kicad_sch, mdc.kicad_pcb, mdc.kicad_sch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]
2026-08-12 update layout prints
2026-08-24 added rev3.1 + some ML adjustments
    [generator_load.kicad_sch, mdc.kicad_pcb, mdc.kicad_sch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]
